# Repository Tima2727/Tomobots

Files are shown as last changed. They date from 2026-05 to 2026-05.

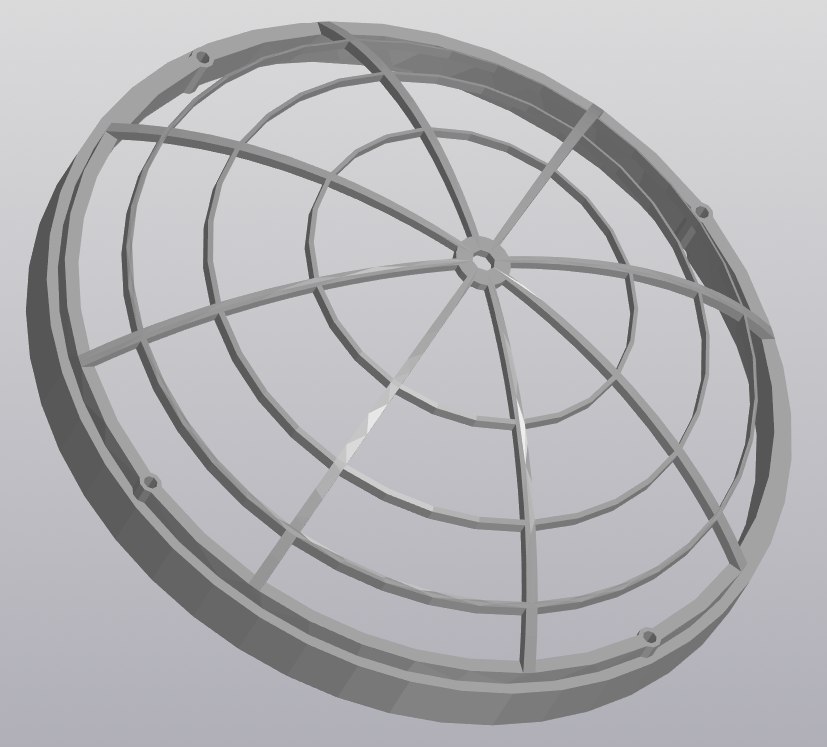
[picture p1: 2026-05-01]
Case/Photos/Lower_part.jpg

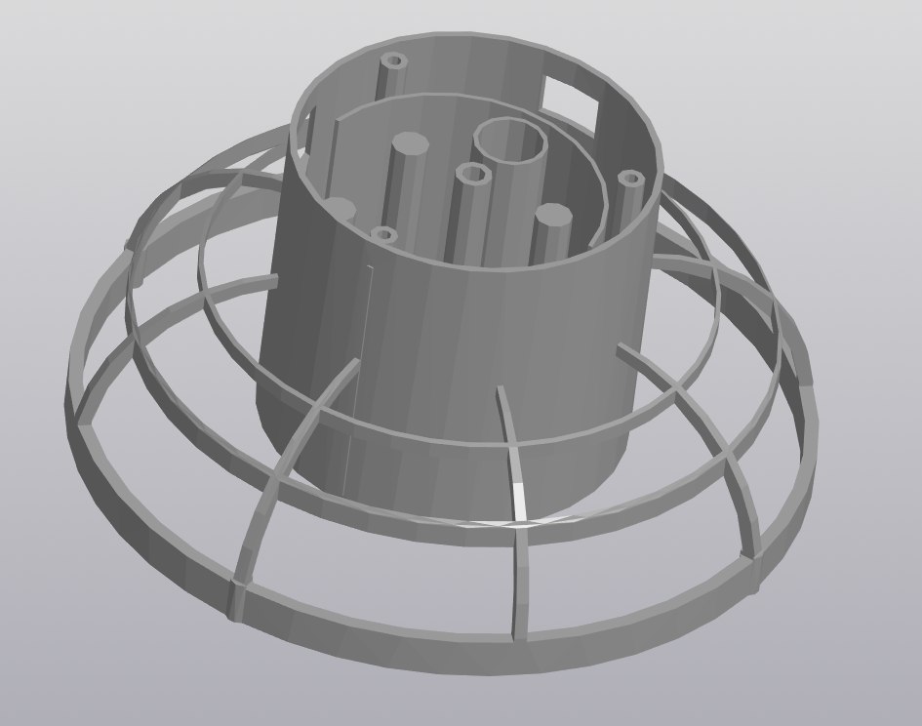
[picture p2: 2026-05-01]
Case/Photos/Upper_part.jpg

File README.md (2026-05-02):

# Tomobots: Роевая система роботов для поиска людей в завалах

**Tomobots** — это инженерный проект по разработке роя компактных и дешевых автономных роботов, предназначенных для первичной разведки в зонах обрушений зданий и землетрясений. Система призвана заменить дорогостоящие и крупногабаритные платформы, обеспечивая быструю локализацию пострадавших даже в труднодоступных «карманах» и щелях.

## Основные особенности

* **Роевая архитектура**: Массовое развертывание сотен простых устройств делает систему устойчивой к потере отдельных единиц.
* **Уникальная проходимость**: Роботы имеют тарелкообразную форму (диаметр 8-10 см) и симметричную конструкцию, позволяющую продолжать движение даже после переворачивания.
* **Низкая себестоимость**: Ориентировочная стоимость в сотни раз меньше аналогов.
* **Ретрансляционная сеть**: При обнаружении человека роботы формируют цепочку передачи радиосигнала до поверхности без необходимости в сложной навигации.

## Технические характеристики прототипа

| Параметр | Значение |
| :--- | :--- |
| **Габаритный диаметр** | 10 см |
| **Масса** | 32 г |
| **Вычислительный модуль** | ESP-12 (ESP8266) |
| **Время работы** | ≈ 25 мин |
| **Материал корпуса** | PLA |

## Алгоритм работы

1.  **Развертывание**: В зону завала запускается партия из ~100 роботов.
2.  **Зондирование**: Роботы выполняют циклы коротких взлетов и хаотичных перемещений.
3.  **Активация**: Пострадавший нажимает высококонтрастную кнопку на роботе.
4.  **Режим маяка**: Активированный робот включает яркую RGB-подсветку и начинает передачу сигнала.
5.  **Локализация**: Ближайшие роботы ретранслируют сигнал на поверхность, где система антенн определяет примерное местоположение цели.

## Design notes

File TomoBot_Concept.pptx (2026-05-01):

## TomoBot

Маленькие роботы для больших вызовов

Университет ИТМО
Санкт-Петербург
01 сентября 2025

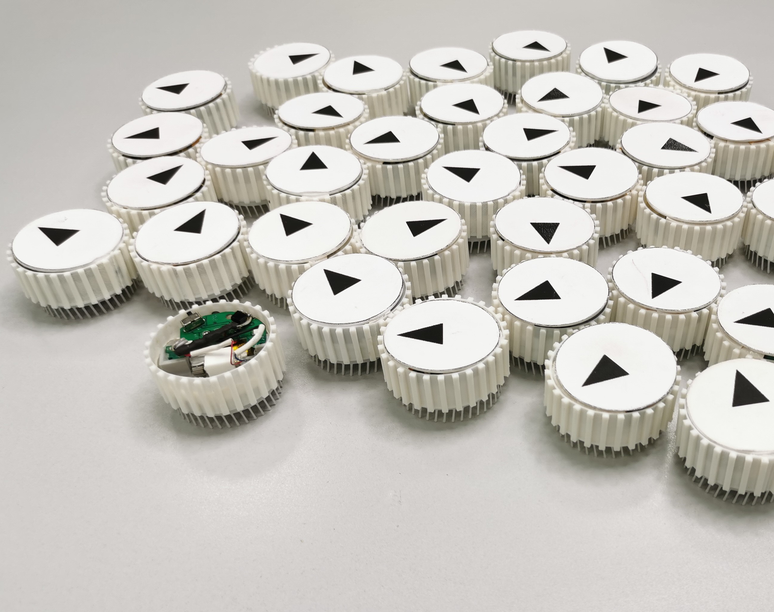
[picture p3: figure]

## Исследование завалов и опасных сред

Большой рой роботов по 800р вместо одного дорогого робота или эндоскопа

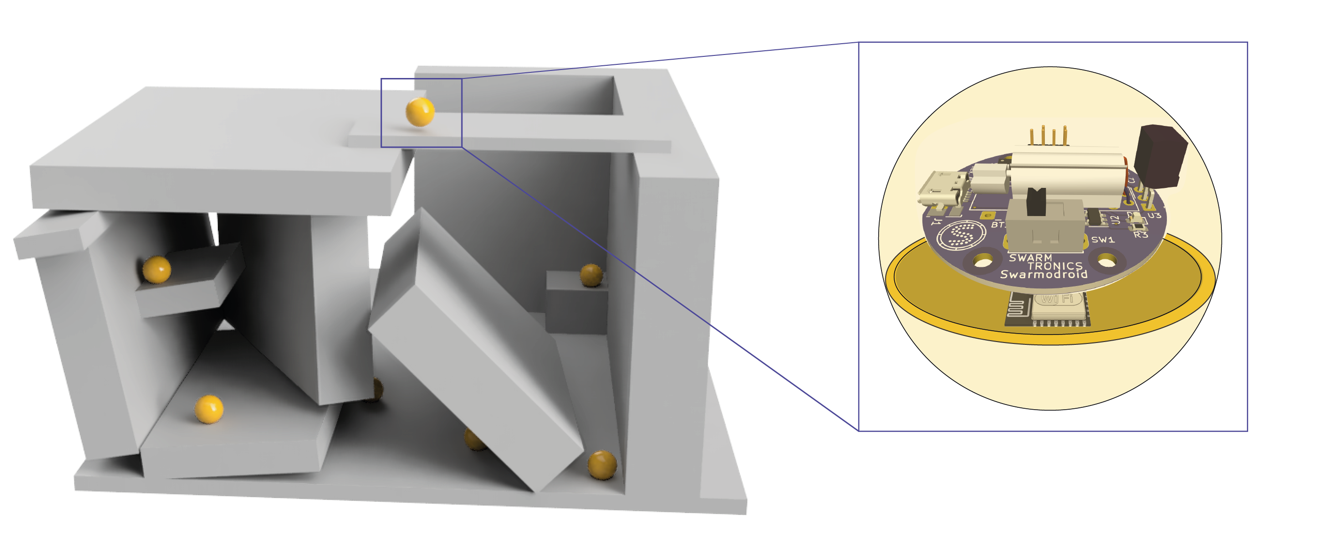
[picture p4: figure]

Цель: определять геометрию завала и число людей в сознании за несколько минут

- Радиомаяк
- LED
- Кнопка для сигнала бедствия

TRL 1

## Исследование завалов и опасных сред

Идея:

Wicked Ball

ESP8266

Wi-Fi tomography

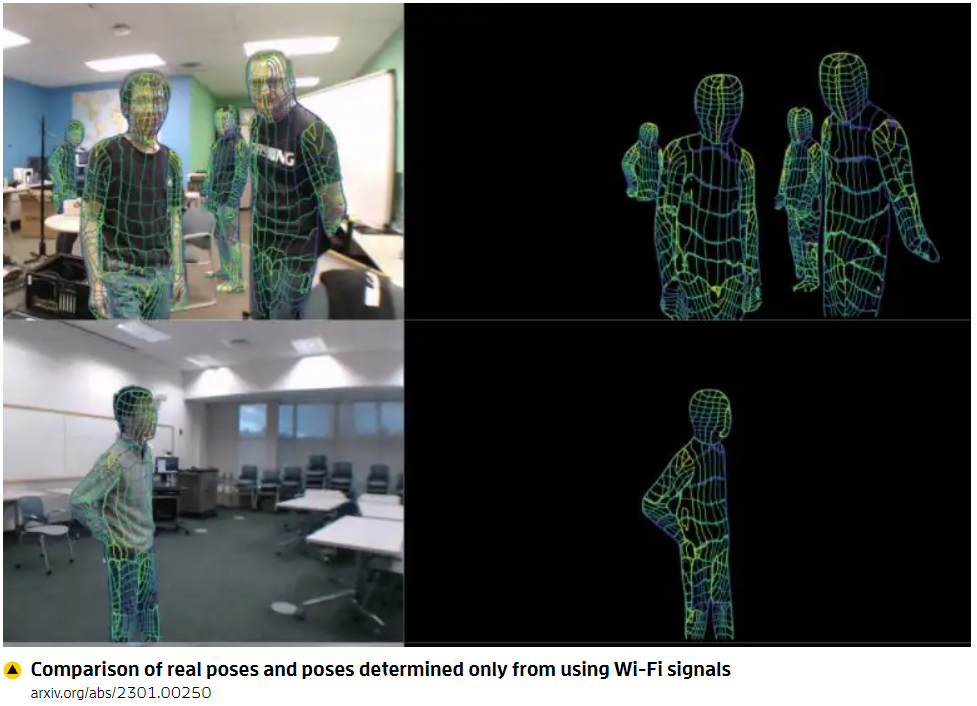
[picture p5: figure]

J. Geng, et al., DensePose From WiFi (2023)
https://arxiv.org/abs/2301.00250

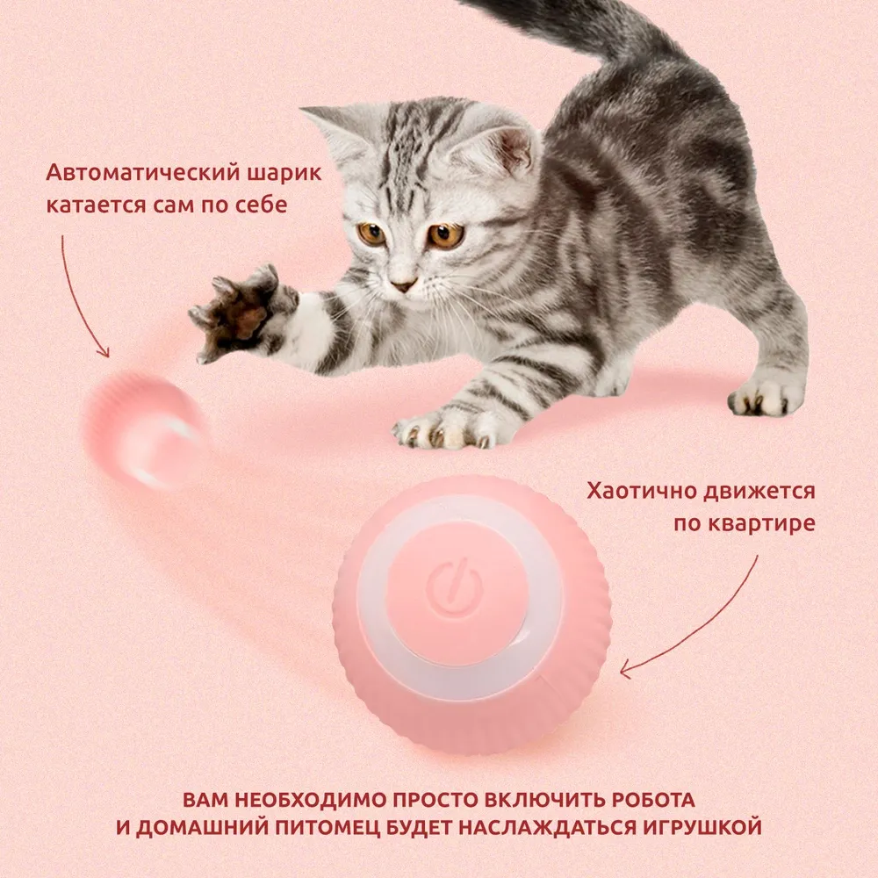
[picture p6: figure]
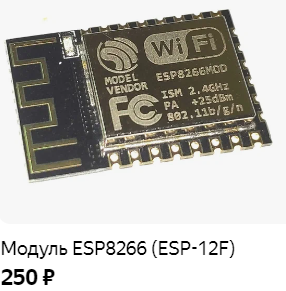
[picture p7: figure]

+

+

## Контакты

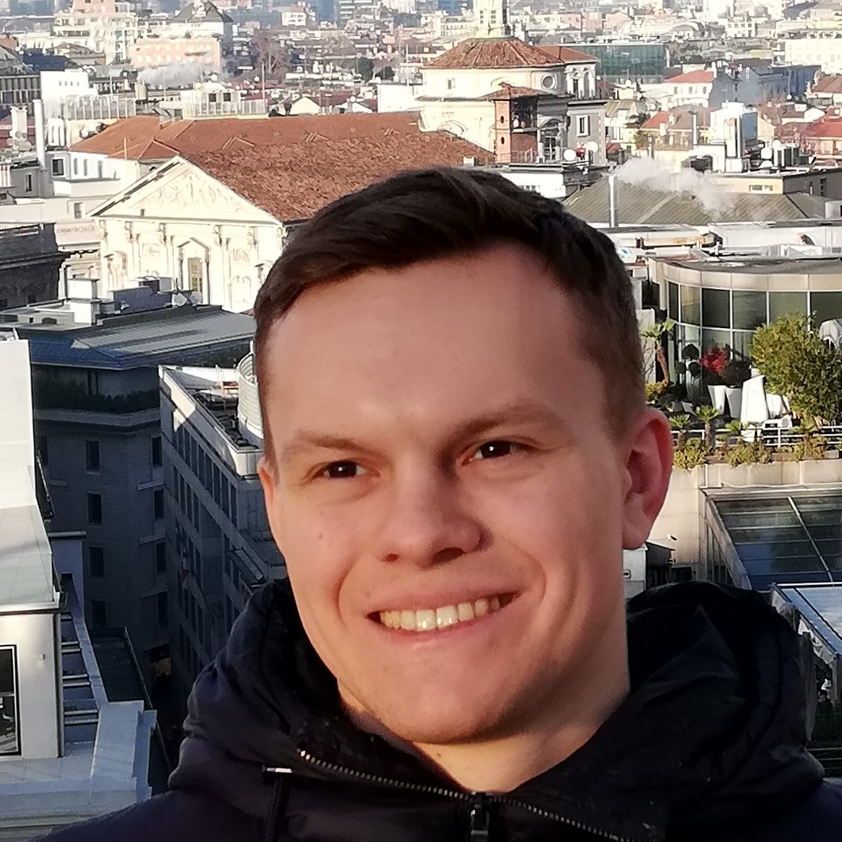
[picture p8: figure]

Никита Олехно
nikita.olekhno@metalab.ifmo.ru

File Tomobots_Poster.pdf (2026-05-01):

СОЗДАНИЕ НОВОГО КОРПУСА И НОВОЙ ПЕЧАТНОЙ ПЛАТЫ, ИХ ИСПЫТАНИЕ.
РАЗРАБОТКА ПРОТОКОЛА СВЯЗИ МЕЖДУ РОБОТАМИ И СИСТЕМОЙ АНТЕНН НА ПОВЕРХНОСТИ.
РАЗРАБОТКА | КОНФИГ УРАЦИИ | ПРИЕМНЫХ | АНТЕНН | И
ПРОГРАММНОГО ОБЕСПЕЧЕНИЯ ДЛЯ ОБРАБОТКИ ПОСТ УПАЮЩИХ ИЗ ЗАВАЛА СИГНАЛОВ.
ПОЛЕВЫЕ | ИСПЫТАНИЯ | РОЯ | РОБОТОВ | В | УСЛОВИЯХ.
ИМИТИРУЮШИХ ЗАВАЛ.

ДОПОЛНЕНИЕ РОБОТА ИК-ДАТЧИКОМ ДЛЯ ОБНАРУЖЕНИЯ ТЕПЛОВОГО ИЗЛУЧЕНИЯ ЧЕЛОВЕКА. РЕАЛИЗАЦИЯ ПОИСКА МОБИЛЬНЫХ ТЕЛЕФОНОВ С ПОМОЩЬЮ WI-FI-МОДУЛЯ.
ДОБАВЛЕНИЕ ДАТЧИКА ДАВЛЕНИЯ ДЛЯ ОЦЕНКИ ГЛУБИНЫ И БОЛЕЕ ИНФОРМАТИВНОГО ОБСЛЕДОВАНИЯ ПОЛОСТЕЙ. ИСПОЛЬЗОВАНИЕ ЛЕТАЮЩИХ РОБОТОВ КАК ПОДВИЖНЫХ УЗЛОВ ДЛЯ ПОСТРОЕНИЯ КАРТЫ ЗАВАЛА (ФУНКЦИЯ ТОМОГРАФИИ).

ПРОБЛЕМА РАЗВЕДКИ В ЗАВАЛАХ: УЗКИЕ ЩЕЛИ (<30 СМ), НЕСТАБИЛЬНОСТЬ ПОСТРОЕК, ПЫЛЬ.
СУЩЕСТВУЮЩИЕ РОБОТЫ ЧАСТО БОЛЬШИЕ, ДОРОГИЕ И ПЛОХО АДАПТИРУЮТСЯ К ИЗМЕНЯЮЩИМСЯ УСЛОВИЯМ.

НАШЕ РЕШЕНИЕ: МАССОВЫЙ ЗАПУСК РОЯ МАЛЕНЬКИХ ДЕШЁВЫХ, ЛЕТАЮЩИХ РОБОТОВ, ПОТЕРЯ ЧАСТИ КОТОРЫХ НЕ НЕСЁТ УЩЕРБА ВСЕЙ СИСТЕМЕ.

# АЛГОРИТМ РАБОТЫ

### 1. РАЗВЁРТЫВАНИЕ

С | ПОВЕРХНОСТИ | ЗАВАЛА | В | НЕСКОЛЬКИХ | ТОЧКАХ
ВЫПУСКАЕТСЯ ПОРЯДКА СОТНИ РОБОТОВ.

### 2. ЗОНДИРОВАНИЕ

КАЖДЫЙ РОБОТ ОСУЩЕСТВЛЯЕТ ХАОТИЧНОЕ ДВИЖЕНИЕ С ПАУЗАМИ — ЭТО ПРЕДОСТАВЛЯЕТ РОЮ ВОЗМОЖНОСТЬ ОБСЛЕДОВАТЬ РАЗЛИЧНЫЕ УРОВНИ И ПОЛОСТИ.

3.ОБНАРУЖЕНИЕ
РОБОТ | ОСНАЩЁН | КРУПНОЙ | КНОПКОЙ | С | ЯРКОЙ
ПОДСВЕТКОЙ. ПОСТРАДАВШИЙ, ЗАМЕТИВ ЕГО, АК ТИВИРУЕТ КНОПКУ. РОБОТ НЕМЕДЛЕННО ФИКСИРУЕТ КОНТАК Т И ПЕРЕКЛЮЧАЕТСЯ В РЕЖИМ МАЯКА.

4.ОРГАНИЗАЦИЯ СЕТИ
В | РЕЖИМЕ | МАЯКА | РОБОТ | НАЧИНАЕТ | ПОСТОЯННО
ПЕРЕДАВАТЬ СИГНАЛ О НАЙДЕННОМ ЧЕЛОВЕКЕ И СВОЙ ИДЕНТИФИКАЦИОННЫЙ НОМЕР. БЛИЖАЙШИЕ К НЕМУ РОБОТЫ, ПОЛУЧИВ СИГНАЛ, РЕТРАНСЛИРУЮТ ЕГО ДАЛЬШЕ ПО ЦЕПИ, ПОКА ОН НЕ ДОСТИГНЕТ ПОВЕРХНОСТИ.

### 5. ЛОКАЛИЗАЦИЯ

УСТАНОВЛЕННАЯ НА ПОВЕРХНОСТИ УСИСТЕМА ИЗ АНТЕНН ЛОКАЛИЗУЕТ ПРИШЕДШИЙ СИГНАЛ И ПО КОЛИЧЕСТВУ ПОЛУЧЕННЫХ СИГНАЛОВ ИЗ ОПРЕДЕЛЁННОЙ ОБЛАСТИ ПОЗВОЛЯЕТ ОЦЕНИТЬ МЕСТОПОЛОЖЕНИЕ ПОСТРАДАВШИХ.

РОЙ АВТОНОМНЫХ ЛЕТАЮЩИХ МИКРОРОБОТОВ Д Л Я ПОИСК А ЛЮД

# TOMOBOTS

ЕЙ В ЗАВА Л А Х

КОМАНД А: Т. ВЕЧК АНОВ, В. ТИМОФЕЕВ, В. ЛЕЗАРЕВ РУКОВОДИТЕЛИ: Н.А. ОЛЕХНО, А.А. ДМИТРИЕВ

# ПРОТОТИП

1) КРЫШКИ НА КОНЦАХ ВАЛА
2) МОДУЛЬ ESP-12
3) БЕСКОЛЛЕКТОРНЫЙ МОТОР
4) АККУМУЛЯТОР
5) ЛОПАСТИ
6) СЕТЧАТЫЙ КОРПУС
7) ОСЕВОЙ ВАЛ

СТРУКТУРА ПРОТОТИПА

ПРИНЦИПИАЛЬНАЯ СХЕМА ПРОТОТИПА

ПРОТОТИП | ПРЕДСТАВЛЯЕТ | СОБОЙ | ПОДВИЖНУЮ
ПЛАТФОРМУ | ЭЛЛИПСОИДАЛЬНОЙ | ФОРМЫ,
ПОВТОРЯЮЩУЮ ГЕОМЕТРИЮ БУДУЩЕГО ЛЕТАЮЩЕГО РОБОТА. В НЁМ ИНТЕГРИРОВАНЫ ВСЕ ОСНОВНЫЕ КОМПОНЕНТЫ ФИНАЛЬНОЙ КОНСТРУКЦИИ.

ОСНОВНЫЕ КОМПОНЕНТЫ СХЕМЫ

### 1. МОДУЛЬ ESP-12 (U1) 2. БЕСКОЛЛЕК ТОРНЫЙ МОТОР QX-6A-N (M1) 3. АККУМУЛЯТОР LP601120 3.7В (BT1) 4. СВЕТОДИОД TO-2013BC-MRE (D1) 5. РАЗЪЁМ MICRO-USB KLS1-233-0-0-1-T (J1) 6. КОНТРОЛЛЕР ЗАРЯДА STC4054 (U3)

# АКТУАЛЬНОСТЬ

# ПЛАНЫ РАЗВИТИЯ

СЛЕДУЮЩИЙ СЕМЕСТР

ПЕРСПЕКТИВА

РАСПОЛОЖЕНИЕ ЭЛЕМЕНТОВ

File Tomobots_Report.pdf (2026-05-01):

Университет ИТМО

Физический факультет

Отчет по семестровому инженерному

проекту

## Tomobots

Исполнители: Тимофеев Вячеслав Вечканов Тимофей Лезарев Всеволод

Руководители: Никита Олехно
| Алексей Дмитриев

Санкт-Петербург
2026

## Содержание

1 Актуальность | 2
2 Схема решения | 3
3 Экономико-техническое обоснование | 5
4 Прототип | 6
5 Инструкция для пользователя | 11
6 Команда проекта | 12
7 План дальнейшего развития | 13
Список источников | 16

## 1 Актуальность

### 1.1 Общие сведения о завалах

В случаях, когда происходят обрушения зданий и землетрясения, первичная разведка значительно осложняется множеством физических ограничений, таких как: узкие проёмы, неустойчивые опорные плоскости, запылённость и фактическая нулевая видимость. Типовые схемы обрушений формируют «карманы» и щели, недоступные для человека и габаритной техники. Критическим фактором становится время: чем быстрее удаётся обнаружить и локализовать пострадавших, тем выше шанс успешной эвакуации.

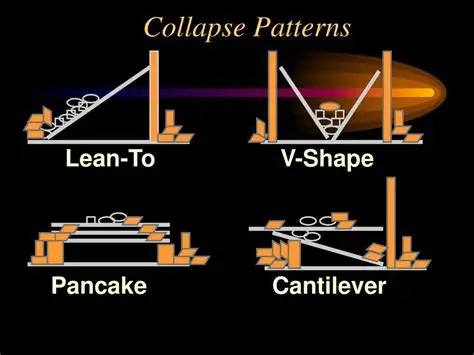
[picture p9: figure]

Рис. 1: Схематично: типовые схемы обрушения (из [4]).

Практика стандартизированных испытаний и инженерные источники указывают на характерные «узкие места» порядка 20–30 см и наклонные осыпи с углами около 30◦ −45◦
(по данным из [1, 3]), что требует компактных и устойчивых к опрокидыванию систем. На этом фоне востребованы решения, которые можно массово развернуть за минуты, которые безопасны при контакте с завалом, допускают потерю отдельных единиц без провала миссии и предоставляют спасателям однозначную «наводку» на человека.

### 1.2 Обзор существующих решений

Наземные платформы (гусеничные/колёсные):
В реальных завалах существующие системы часто физически не проходят в локальные пустоты; к тому же масса и стоимость остаются высокими, а риск заклинивания велик ([1]). Сильные стороны — высокая грузоподъёмность, манипуляторы, длительная работа; слабые — ограниченная проходимость, необходимость подготовленных маршрутов и стоимость.

Воздушные решения (квадрокоптеры, БПЛА):
Складывающиеся и трансформируемые конструкции демонстрируют проникновение в стеснённые пространства и пролёты через узкие проёмы ([11, 10]). Однако в завалах им мешают пыль, ограниченная энергоёмкость, отсутствие стабильной навигации и связи, а удар по лопастям ведёт к отказу. Управление в тесных каналах требует высокой квалификации пилота или сложной автономии.

Роевые и недорогие платформы:
Опыт работы платформ вроде [9, 8] показывает, что сотни простых роботов могут работать вместе и не «ломаются» как система, даже если часть из них выходит из строя. Но есть важные ограничения: данные эксперименты проводятся на ровных лабораторных площадках, что оставляет октрытым вопрос о надёжности связи и ориентирования в условиях завалов. Кроме того, роботы должны пролезать через узкие места, экономно расходовать энергию и пробивать радиосигналом путь к поверхности.

Вывод

Текущие решения покрывают отдельные сценарии, однако на сегодняшний день существует необходимость их объединения и создания вариантов, которые одновременно: компактны и безопасны при контакте с обломками, дёшевы в масштабировании до сотен экземпляров и сохраняют функциональность при перевороте/ударе.

Предлагаемый подход:
Мы закрываем этот пробел роевой системой компактных роботов-маяков: они хаотично обследуют завал, а при активации пострадавшим формируют ретрансляционную цепочку до поверхности, обеспечивая быструю локализацию без сложной картографии и дорогостоящих сенсоров. Это сочетает массовое развёртывание, отказоустойчивость роя и триггерную детекцию человеком.

## 2 Схема решения

### 2.1 Алгоритм работы роя роботов

Проектом разрабатывается система на базе роя автономных летающих роботов тарелкообразной формы (диаметр 8-10 см). Система функционирует по следующему алгоритму:

1. Массовое развертывание. С поверхности завала в нескольких точках выпускается порядка сотни роботов.

2. Пассивно-активное зондирование. Каждый робот осуществляет хаотичное движение в объёме завала. Алгоритм полёта предполагает циклическое выполнение коротких взлётов, горизонтальных перемещений в случайном направлении и пауз, при которых робот не двигается. Взлёты осуществляются поочерёдно в обоих направлениях за счёт симметричных лопастей и смены полярностей на моторе, благодаря чему робот продолжает функционировать при переворачивании. Это позволяет роботу обследовать различные уровни и полости, а также предоставляет временное окно для взаимодействия с пострадавшим.
3. Обнаружение и активация. Робот оснащён высококонтрастной кнопкой с подсветкой. Пострадавший, обнаружив рядом робота, нажимает кнопку, после чего робот начинает передавать сигнал о найденном человеке.
4. Организация ретрансляционной сети. Активированный робот переходит в режим маяка. Он начинает постоянно светиться и передавать сигнал о найденном человеке и свой идентификационный номером. Близжайщие из роя роботы, получив сигнал, ретранслируют его дальше по цепи, пока он не выберется на поверхность.
5. Локализация пострадавших. На поверхности устанавливается система из антенн, которая локализует пришедший сигнал и по количеству полученных сигналов из определённой области позволяет приблизительно оценить местоположение пострадавших.

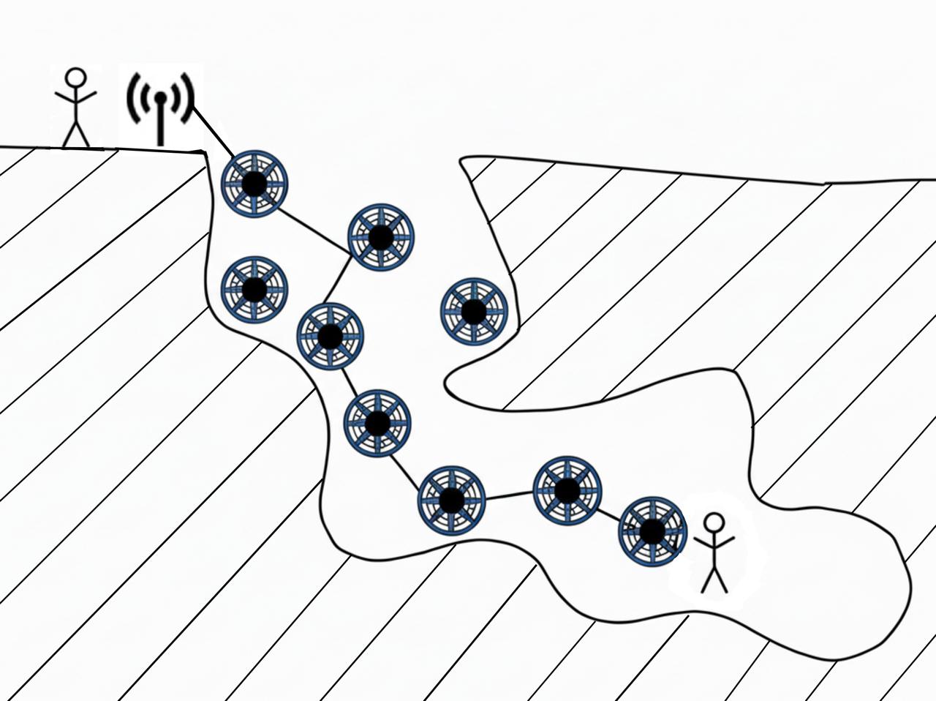
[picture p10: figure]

Рис. 2: Схема работы роботов

### 2.2 Физико-технические основы

Динамика:
Сетчатый корпус минимизирует массу и обеспечивает проход воздуха от расположенного внутри пропеллера. Также ось вращения пропеллера выходит из корпуса и на ее концах оснащена специальными крышками, так что при работе пропеллера на малых оборотах крышки также вращаются и цепляются за землю, за счёт чего обеспечивается хаотичное передвижение в горизонтальном направлении.

Управление:
Полетная логика (взлёт/падение, случайные смещения) реализована на программируемом модуле ESP-12, который управляет мотором, обеспечивающим вращение лопастей.

Связь:
Для организации надёжной многоузловой сети разрабатывается специальный протокол связи в нелицензируемом ISM-диапазоне, оптимизированный для низкой скорости передачи данных, но высокой помехоустойчивости.

## 3 Экономико-техническое обоснование

Вычислительная платформа:
Программируемый Wi-fi модуль (на базе ESP8266).
Обоснование: наличие встроенного Wi-Fi/радиомодуля, достаточная для базовой логики производительность, низкая стоимость, возможность программирования в Arduino IDE.

Корпус:
3D-печать методом FDM из лёгкого PLA или PETG с решётчатой структурой. Обоснование: высокие скорость прототипирования и потенциал масштабирования, формирование сложных аэродинамических форм при минимальной массе.

Энергосистема:
Литий-полимерный аккумулятор (Li-Po) малой ёмкости (110 мА·ч). Обоснование: достаточная ёмкость и малые габариты.

Cистема реагирования:
Кнопка с защитой от ложных срабатываний, RGB-светодиод высокой яркости. Обоснование: стабильное срабатывание кнопки только от нажатий человека, легкость в её обнаружении.

В смете (Таблица 1) указаны компоненты, которые будут использоваться в финальной версии роботов.

Таблица 1: Смета на одного Tomobot’а
Наименование | Ед. изм. | Стоимость, руб | Кол-во | Сумма, руб
Модуль ESP-12 (ESP8266) Бесколлекторный мотор Аккумулятор Светодиод TO-2013BC-MRE Драйвер мотора L9110S Переключатель Ось привода (вал) Разъём micro-USB KLS1-233-0-0-1-T Контроллер заряда STC4054 Стабилизатор питания AMS1117-3.3V Транзистор AO3400 Резистор 10k Резистор 680 Резистор 5k1 Конденсатор 100нФ | шт. шт. шт. шт. шт. шт. шт. шт. шт. шт. шт. шт. шт. шт. шт. | 190 600 500 8 20 11 8 11 130 6 4 0.7 0.7 0.7 2 | 1 1 1 1 1 1 1 1 1 1 1 2 1 1 1 | 190 600 500 8 20 11 8 11 130 6 4 1.4 0.7 0.7 2
Итого | | | | 1493.8

В отличие от аналогов, наша система имеет ориентировочную себестоимость одного робота около 1500 рублей.

Это обеспечивает беспрецедентное ценовое преимущество. Например, для обследования типового завала площадью 100 м² потребуется около 200 роботов. Стоимость такой партии составит около 300 000 рублей. Для сравнения, один гусеничный робот сопоставимой функциональности стоит от 500 000 рублей, при этом он не способен одновременно охватывать множество полостей и не обладает отказоустойчивостью роя.

## 4 Прототип

На текущем этапе разработан и собран функциональный прототип робота, предназначенный для экспериментальной отработки ключевых принципов работы системы: механизма перемещения, базовой логики поведения и интеграции электронных компонентов.

### 4.1 Конструкция и состав

Прототип представляет собой наземную подвижную платформу тарелкообразной формы, повторяющую целевую геометрию будущего летающего робота (Рис. 3). В нём интегрированы все основные компоненты финальной конструкции, за исключением драйвера силового мотора, что позволило сосредоточиться на изучении динамики и управлении:

1. Программируемый Wi-fi модуль ESP12 (ESP8266) в качестве вычислительного ядра.
2. Бесколлекторный мотор, вращающий лопасти на оси.
3. Система питания на базе Li-Po аккумулятора ёмкостью 110 мА·ч с контроллером заряда TC4054 и стабилизатором напряжения AMS1117.

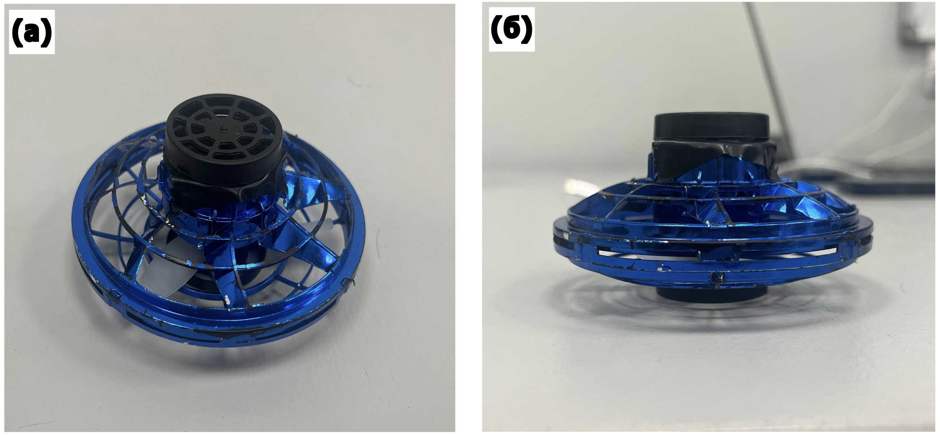
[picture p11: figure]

Рис. 3: Фотография собранного прототипа.

### 4.2 Принцип работы прототипа

Прототип реализует механизм хаотичного наземного перемещения. При вращении мотора лопасти, закреплённые на выступающей оси, взаимодействуют с опорной поверхностью. На малых оборотах специальные крышки на концах оси цепляются за грунт, обеспечивая случайные поступательные смещения и вращение корпуса. Данный режим является упрощённым аналогом фазы «паузы и смещения» в целевом алгоритме полёта и служит для изучения поведения робота в контакте с неструктурированной поверхностью, имитирующей завал.

### 4.3 Электрическая схема и модель корпуса

Для обеспечения повторяемости и дальнейшей разработки подготовлена полная документация прототипа. Также в смете (Таблица 2) указаны компоненты, используемые в прототипе.

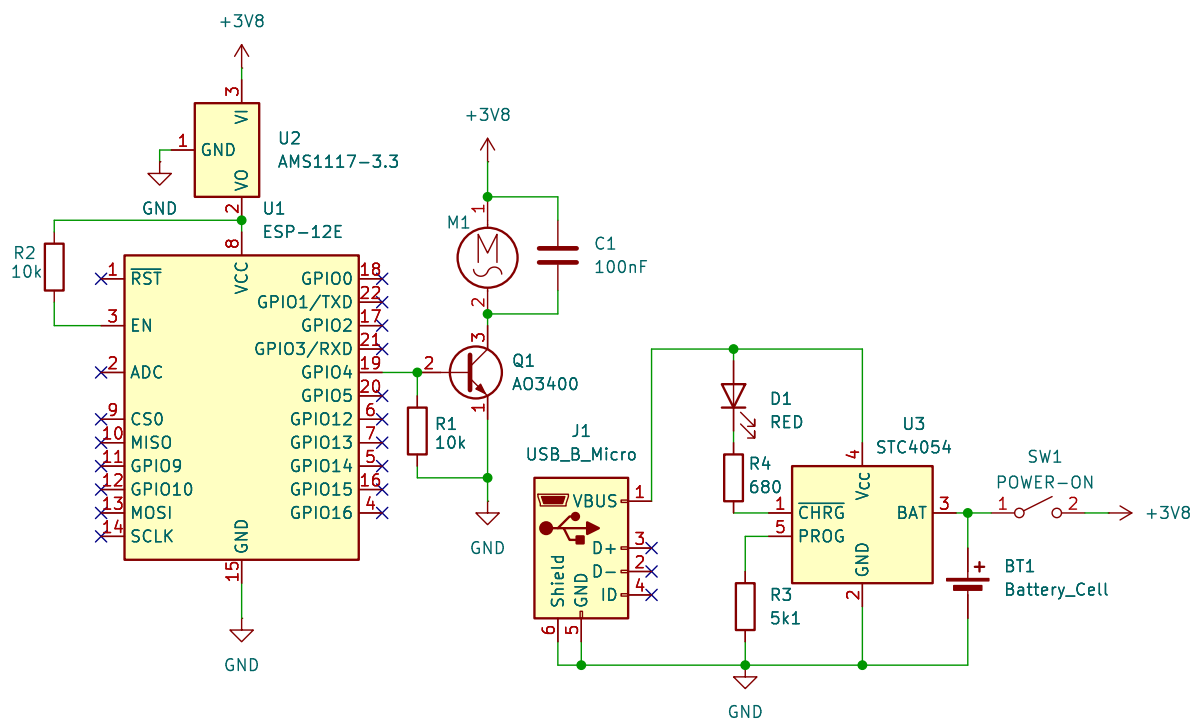
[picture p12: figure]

Рис. 4: Электрическая принципиальная схема прототипа.

На рисунке 4 изображена схема электрическая принципиальная прототипа. Для управления мотором M1, QX-6A-N и для приёма-отправки сигналов используется модуль ESP-12E, питание 3.3В к нему поступает через стабилизатор напряжения U2, который понижает исходное нпряжение питания от батарейки BT1 3.8В до напряжения соответственно необходимого для работы модуля ESP-12E. Для включения модуля также необходимо напряжение на пине EN, который соответственно через токоограничительный резистор R2 соединен с питанием модуля. На выход GPIO4 согласно прошивке модуля циклически подаётся различный широтно-импульсно модулированный сигнал с высоким логическим уровнем 3.3В. При высоком логическом уровне полевой транзистор Q1 открыт и соответствующий полюс мотора соединен с общим проводом. Параллельно мотору установлен конденсатор C1, сглаживающий ШИМ при низких частотах. Также к GPIO4 подсоединен подтягивающий резистор R1 к общему проводу, необходимый для фиксирования низкого логического уровня и предотвращения ложных срабатываний. Для зарядки используется порт Micro-USB, который соединён с контроллером зарядки STC4054. К пину CHRG через токоограничительный резистор R4 подключен диод D1, который является индикатором зарядки. Пин PROG соединен с общим проводом через резистор R3, что устанавливает ограничение тока зарядки батареи. Положительный контакт батареи соединён с пином BAT, отрицательный с общим проводом. На выходе питания установлен переключатель SW1, который отвечает за перевод робота во включенное состояние и наоборот.

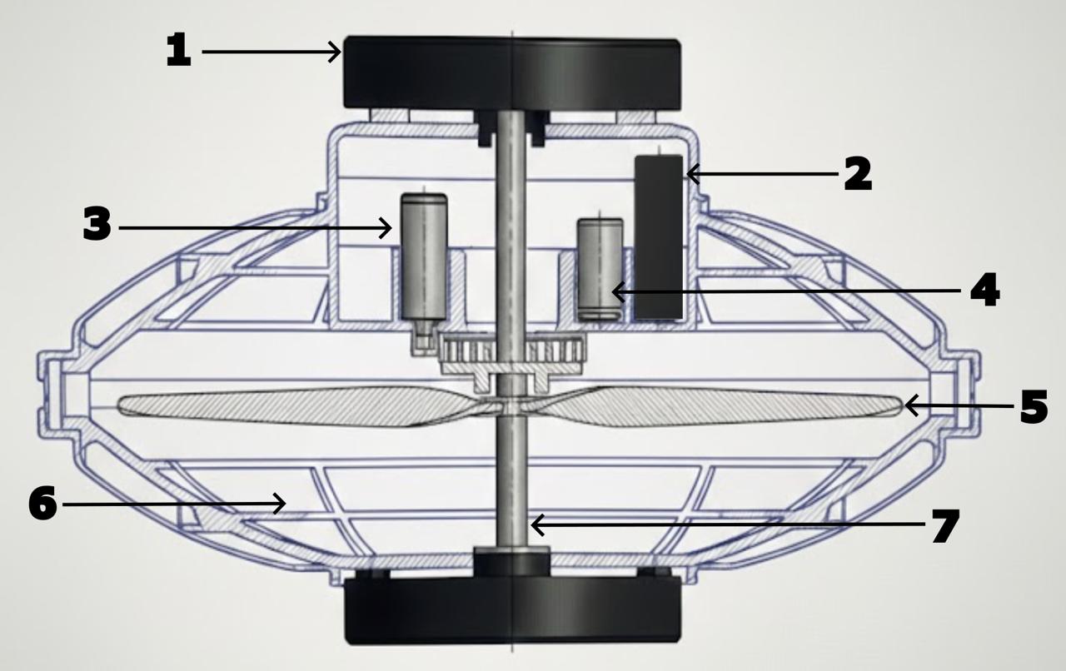
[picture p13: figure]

Рис. 5: Схематичный рисунок робота в разрезе: 1) Крышки на концах вала
2) Додуль ESP-12 3) Бесколлекторный мотор 4) Аккумулятор 5) Лопасти 6) Сетчатый корпус 7) Осевой вал

Таблица 2: Смета прототипа
Наименование | Ед. изм. | Стоимость, руб | Кол-во | Сумма, руб
Модуль ESP-12 (ESP8266) Бесколлекторный мотор QX-6A-N Аккумулятор LP601120 3.7 В Светодиод TO-2013BC-MRE Переключатель Ось привода (вал) Разъём micro-USB KLS1-233-0-0-1-T Контроллер заряда STC4054 Стабилизатор питания AMS1117-3.3V Транзистор AO3400 Резистор 10k Резистор 680 Резистор 5k1 Конденсатор 100нФ | шт. шт. шт. шт. шт. шт. шт. шт. шт. шт. шт. шт. шт. шт. | 190 175 130 8 11 8 11 130 6 4 0.7 0.7 0.7 2 | 1 1 1 1 1 1 1 1 1 1 2 1 1 1 | 190 175 130 8 11 8 11 130 6 4 1.4 0.7 0.7 2
Итого | | | | 677,8

### 4.4 Измеренные характеристики и выявленные пробле-

мы

В процессе испытаний прототипа были получены следующие ключевые характеристики и определены направления для доработки:

Таблица 3: Основные параметры и результаты испытаний прототипа
Параметр | Результат / Значение
Габаритный диаметр | 10 см
Масса (с аккумулятором) | 32 г
Время непрерывной работы | ≈ 25 мин
Тип перемещения | Случайные вращения и посту-пательные смещения по по-верхности

Выявленная ключевая проблема: Установленный в прототипе мотор не обладает достаточной мощностью для реализации запланированного цикла кратковременных взлётов. Это подтверждает необходимость перехода к более мощному мотору в следующей итерации разработки.

### 4.5 Роль прототипа в проекте

Несмотря на ограничения, текущий прототип успешно выполняет свои задачи:

1. Проверка функциональности: Подтверждена работоспособность и совместимость выбранных компонентов (ESP-12, система питания).
2. Исследование динамики: Изучено поведение корпуса заданной формы при контакте с поверхностью, что критически важно для фазы паузы.
3. Платформа для отладки ПО: Обеспечена возможность тестирования базового кода управления.

Таким образом, данный прототип служит фундаментальным подтверждением возможности создания продукта. На его основе в следующем семестре будет создан полнофункциональный летающий образец с более мощным мотором и доработанным алгоритмом.

## 5 Инструкция для пользователя

### 5.1 Подготовка к работе

Установите по углам исследуемой области приёмные антенны и проверьте их работоспособность в тестовом режиме.

Убедитесь, что все роботы в пусковой партии заряжены (индикатор на устройстве горит зелёным).

Визуально оцените зону завала и выберите 3-5 точек для запуска в предполагаемой зоне поиска.

### 5.2 Запуск

В каждой выбранной точке последовательно выпустите роботов: извлеките из транспортного контейнера и включите питание.

После запуска роботы начнут хаотичное движение внутри завала (короткие взлёты и перемещения с паузами).

### 5.3 Мониторинг

Следите за показаниями в заранее установленном ПО на компьютере/планшете.

Отсутствие сигнала означает, что триггерное событие (обнаружение пострадавшего и нажатие кнопки) ещё не произошло.

### 5.4 Действия при обнаружении

При нажатии пострадавшим кнопки на роботе формируется «цепочка» — маяки фиксируются и светятся; сигнал ретранслируется к поверхности.

Цепочка светящихся роботов указывает направление и примерный путь к пострадавшему.

Начните точечную разборку завала, двигаясь от крайнего (видимого на поверхности) робота вдоль линии зафиксированных маяков.

### 5.5 Возможные проблемы

Приёмник регистрирует слабый или прерывистый сигнал:

Переместитесь по периметру зоны, чтобы найти позицию с лучшим приёмом; цепочка могла сформироваться в глубине, и сигнал пробивается только в отдельных точках.

Робот не взлетает / не реагирует:

Считайте устройство неисправным, аккуратно извлеките его из зоны поиска и замените другим. Система роя рассчитана на отказ отдельных единиц без потери общей функциональности.

## 6 Команда проекта

Название будущего стартапа: Tomobots.

### 6.1 Команда и зоны ответственности

Вечканов Тимофей — инженер (электронная часть). Схемотехника и PCB (ESP-12/ESP8266; драйверы, зарядка и стабилизация питания), прошивка на C/Arduino IDE, проектирование радиопротокола в ISM-диапазоне, стендовые испытания электроники.
Вклад в отчёт: «Схема решения», «Выбор компонентов и технологий», «Связь», «Смета прототипа».

Тимофеев Вячеслав — инженер (механическая часть). CAD-моделирование, 3D-печать (FDM PLA/PETG), конструкция решётчатого корпуса, узел вала
и лопастей, сборка и прочностные/ударные испытания.
Вклад в отчёт: «Прототип», иллюстрации и фото.

Лезарев Всеволод — инженер (интеграция и компановка отчётов). Полевые тесты, ведение репозитория и сборки материалов (презентация/постер). Вклад в отчёт: «Инструкция для пользователя», «План дальнейшего развития», компоновка и форматирование.

### 6.2 Научные руководители

Алексей Дмитриев — научный руководитель. Н.с. Физико-технического факультета, к.ф.-м.н.
Роль в проекте: научная экспертиза, корректность формулировок, финальная проверка текстов.

Никита Олехно — научный руководитель. Доцент Физико-технического факультета, к.ф.-м.н.
Роль в проекте: постановка исследовательских задач, контроль методологии и научной новизны.

### 6.3 Контакты

ФИО | Роль | E-mail
Вечканов Т. Тимофеев В. Лезарев В. Дмитриев А. Олехно Н. | электроника механика интеграция/ПО науч. рук. науч. рук. | timofei.vechkanov@metalab.ifmo.ru v.timofeev@metalab.ifmo.ru vsevolod.lezarev@metalab.ifmo.ru alexey.dmitriev@metalab.ifmo.ru nikita.olekhno@metalab.ifmo.ru

## 7 План дальнейшего развития

### 7.1 Следующий семестр

Создание и апробация изделия:
Новый корпус и новая печатная плата; сборка и функциональные испытания экспериментального образца.

Разработка протокола связи:
Создание и испытание прототипа с базовой логикой полёта (взлёт/посадка/случайное смещение).

Система приёма сигнала и локализации:
Разработка конфигурации приёмных антенн и специализированного ПО для обработки поступающих сигналов.

Интеграция и полевые испытания:
Комплексные испытания роя из 5-10 роботов в условиях, имитирующих завал (лабиринт из труб и картона).

### 7.2 Перспектива

Автономное обнаружение:
Замена/дополнение тактильной кнопки пассивным ИК-датчиком (PIR) для детекции теплового излучения человека; обнаружение близлежащих телефонов с использованием Wi-Fi-модуля.

Улучшение навигации:
Добавление датчика давления для оценки глубины и более интеллектуально-

го обследования полостей.

Гибридная томография:
Использование летающих роботов как подвижных узлов для предварительного построения карты завала на основе анализа уровней принимаемого сигнала между ними и базовыми станциями.

Создание нового корпуса робота: Планируется заменить текущий корпус на новый для упрощения масштабирования производства (Рис. 6, 7).


Рис. 6: Новый корпус: верхняя часть


Рис. 7: Новый корпус: нижняя часть

## Список источников

[1] NIST, ASTM. Standard Test Methods for Response Robots. U.S.
Department | of | Homeland | Security; | NIST/ASTM, | 2017. | URL:
https://www.nist.gov/system/files/documents/el/isd/ms/DHS_NIST_ASTM_Robot_Test_Methods-2.pdf (https://www.nist.gov/system/files/documents/el/isd/ms/DHS_NIST_ASTM_Robot_Test_Methods-2.pdf)
[2] ASTM E54.09, NIST. Response Robots—Ground Tests: Exploration and Mapping (2022A). ASTM/NIST, 2022.
[3] Engineering Toolbox. Angle of Repose for Bulk Materials, 2024. URL: https: //www.engineeringtoolbox.com/dumping-angles-d_1531.html
[4] Downey, R. Types of Building Collapse. FDNY Training Bulletin, 2001. URL: https://www.chiefraymonddowney.com/documents/wnyf/2001%20January%20-%20Types%20of%20Collapse.pdf (https://www.chiefraymonddowney.com/documents/wnyf/2001%20January%20-%20Types%20of%20Collapse.pdf)
[5] Riedl, M. и др. Synchronization in Collectively Moving Inanimate and Living Active Matter // Nature Communications. 2023.
[6] Hidalgo-Caballero, S., Cassinelli, A., Fort, E., Labousse, M. Frugal Random Exploration Strategy for Shape Recognition Using Statistical Geometry // Physical Review Research. 2024. Vol. 6, № 023103.
[7] USAR exploration metrics. Urban Search and Rescue—Exploration & Mapping Metrics, 2019.
[8] Harvard SEAS. Programmable Self-Assembly in a Thousand-Robot Swarm, 2014. URL: https://www.youtube.com/watch?v=6aZbJS6LZbs
[9] Harvard SEAS. Kilobot Swarm, 2011. URL: https://www.youtube.com/watch?v=RMjtmsr3CqA (https://www.youtube.com/watch?v=RMjtmsr3CqA)
[10] Systems and Methods for Foldable/Compact Aerial Robots. Патент
US11448728B2, | 2022. | URL | https://patents.google.com/patent/
US11448728B2 (https://patents.google.com/patent/US11448728B2)
[11] A Compact Morphing Drone for Confined-Space Inspection // Science
Robotics. | 2024. | URL: | https://www.science.org/doi/10.1126/
scirobotics.aee7991 (https://www.science.org/doi/10.1126/scirobotics.aee7991)
[12] Recent Advances in Confined-Space Robotics / Morphing Mechanisms // Nature Communications. 2024.
[13] Wang, Z., Appleton, E. The Bristle Theory and Traction Experiment of a Brush-Based Rescue Robot // Robotica. 2003.
[14] Romanishin, J. W., Gilpin, K., Claici, S., Rus, D. 3D M-Blocks: Self-Reconfiguring Robots Capable of Locomotion via Pivoting in Three Dimensions. 2015.

[15] Fath, M. и др. MARSBot: A Bristle-Bot Microrobot with AR Steering Control. 2024.
[16] Fath, M. и др. HeSARIC: A Heterogeneous Cyber-Physical Robotic Swarm Framework. 2025.
[17] Farrell, J. WiFi Imaging: Generating Building Maps Using Passively Received WiFi Signals., 2021.
[18] Yakub, A. Presence Detection with Wi-Fi Using ESP32. 2024.
[19] Geng, Z. и др. DensePose From WiFi. 2022.

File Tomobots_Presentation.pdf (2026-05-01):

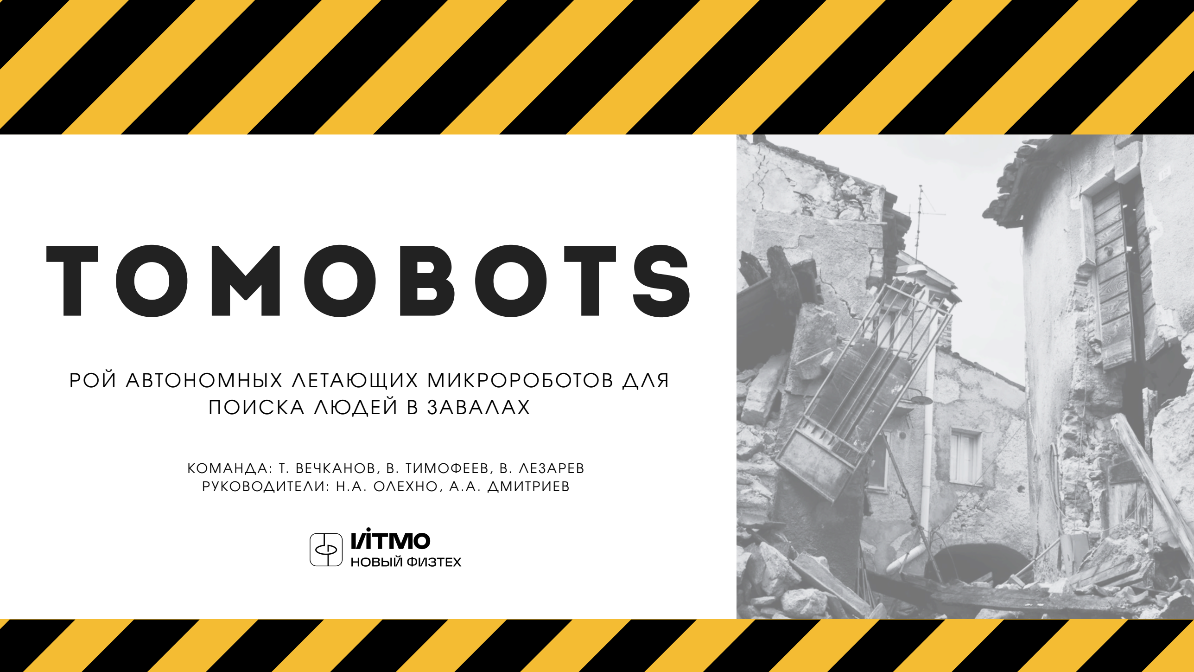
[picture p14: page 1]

# TOMOBOTS

РОЙ АВТОНОМНЫХ ЛЕТАЮЩИХ МИКРОРОБОТОВ ДЛЯ ПОИСКА ЛЮДЕЙ В ЗАВАЛАХ

КОМАНДА: Т. ВЕЧКАНОВ, В. ТИМОФЕЕВ, В. ЛЕЗАРЕВ РУКОВОДИТЕЛИ: Н.А. ОЛЕХНО, А.А. ДМИТРИЕВ

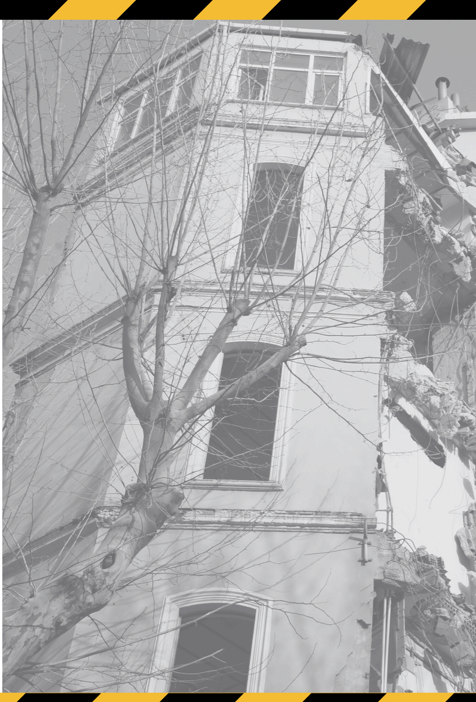
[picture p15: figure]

Узкие | щели | (20-30 | см), | неустойчивость
построек, пыль, нулевая видимость. Критический фактор — время. Существующие решения (гусеничные роботы) неэффективны.

КЛЮЧЕВОЙ ВОПРОС: КАК БЫСТРО И ЭФФЕКТИВНО ОБСЛЕДОВАТЬ НЕДОСТУПНЫЕ ПОЛОСТИ В ЗАВАЛЕ?

# ПРОБЛЕМА И АКТУАЛЬНОСТЬ

# КОНЦЕПЦИЯ РОЯ TOMOBOTS

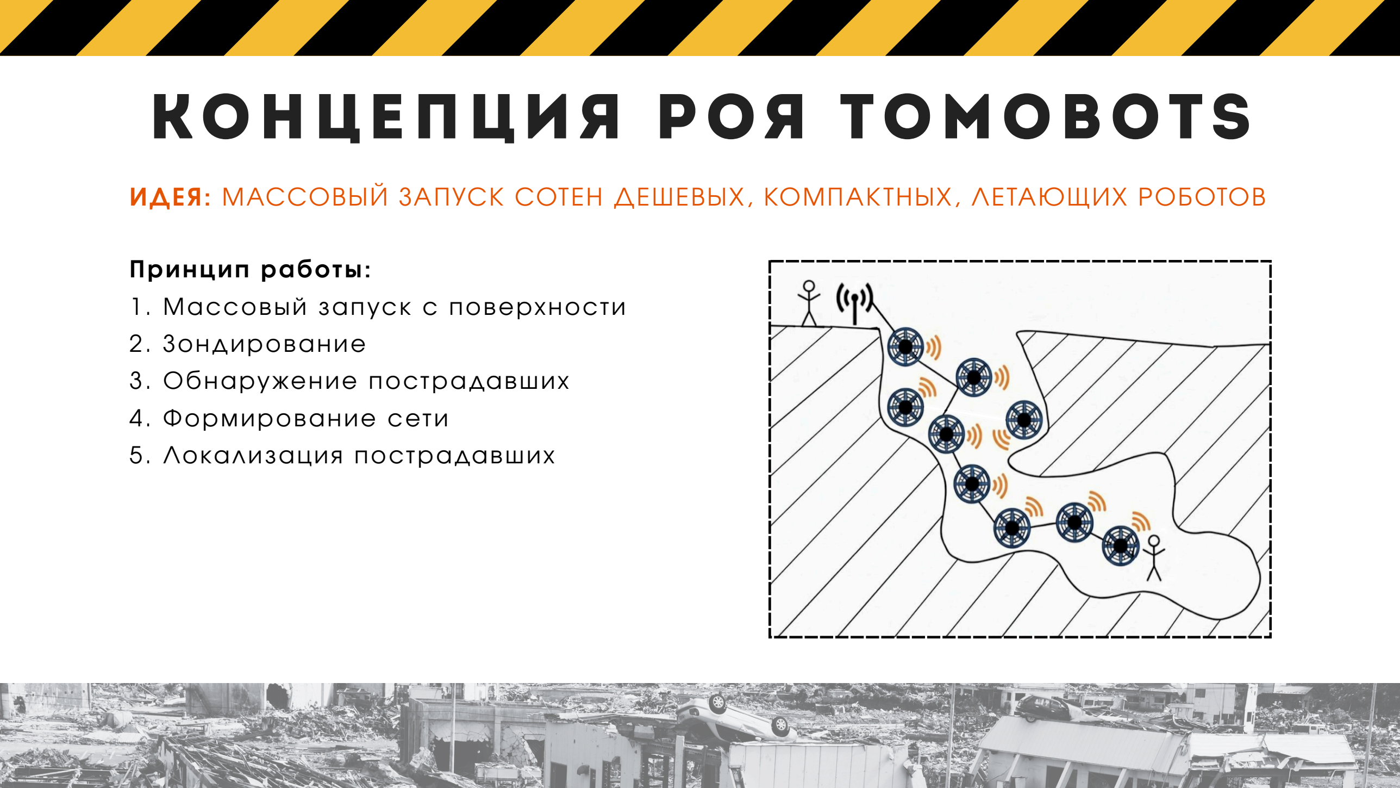
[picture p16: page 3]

ИДЕЯ: МАССОВЫЙ ЗАПУСК СОТЕН ДЕШЕВЫХ, КОМПАКТНЫХ, ЛЕТАЮЩИХ РОБОТОВ

Принцип работы:
1. Массовый запуск с поверхности
2. Зондирование
3. Обнаружение пострадавших
4. Формирование сети
5. Локализация пострадавших

# ПРОТОТИП

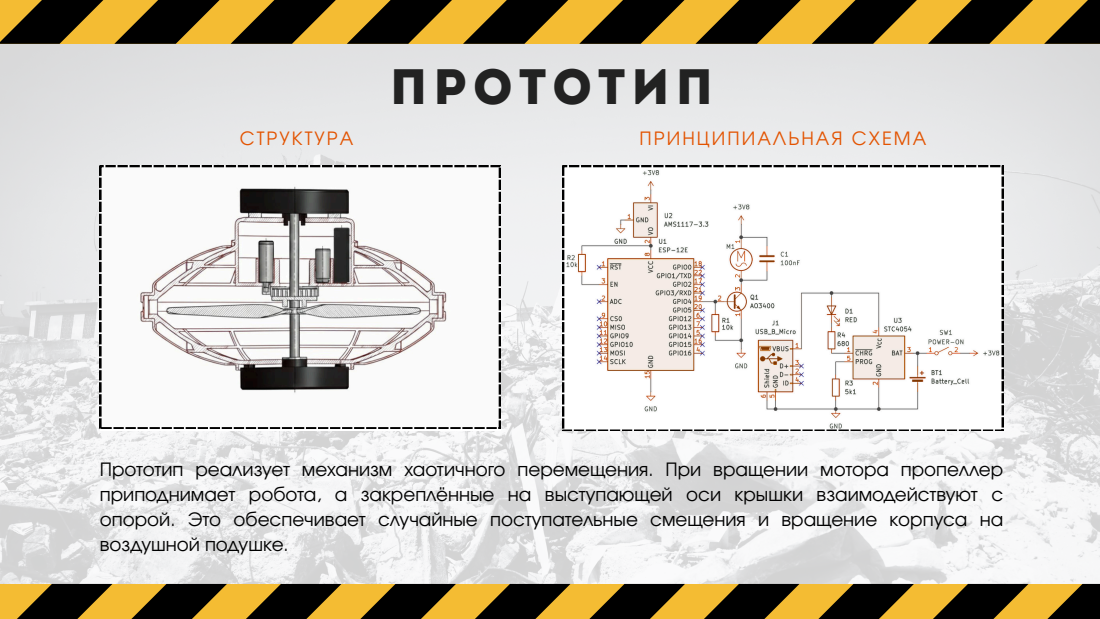
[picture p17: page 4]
СТРУКТУРА; ПРИНЦИПИАЛЬНАЯ СХЕМА

Прототип реализует механизм хаотичного перемещения. При вращении мотора пропеллер
приподнимает робота, а закреплённые на выступающей оси крышки взаимодействуют с
опорой. Это обеспечивает случайные поступательные смещения и вращение корпуса на
воздушной подушке.

# ПЛАН РАЗВИТИЯ

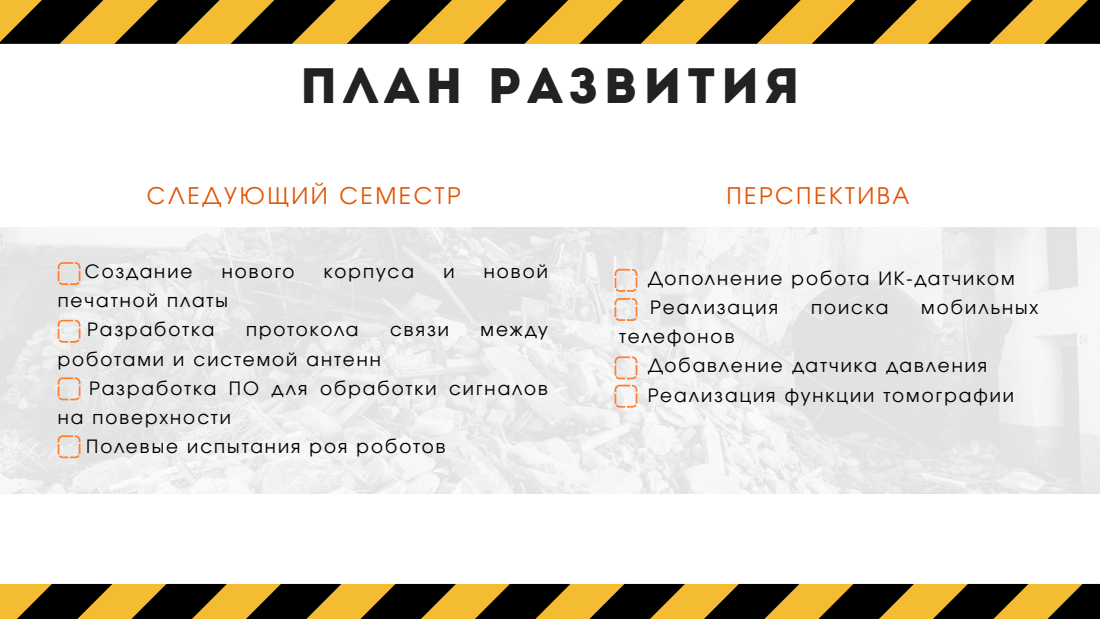
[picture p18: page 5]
Реализация; поиска; мобильных; Создание; нового; корпуса; новой; Разработка; протокола; связи; между; СЛЕДУЮЩИЙ СЕМЕСТР; ПЕРСПЕКТИВА

печатной платы
роботами и системой антенн
Разработка ПО для обработки сигналов
на поверхности
Полевые испытания роя роботов

Дополнение робота ИК-датчиком
телефонов
Добавление датчика давления
Реализация функции томографии

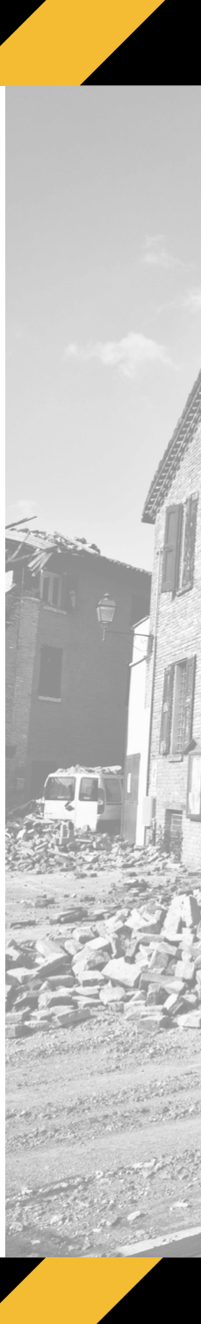
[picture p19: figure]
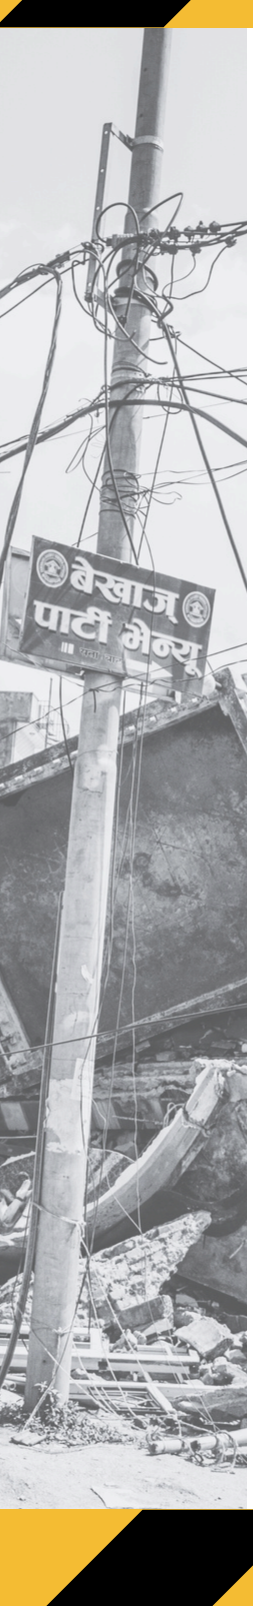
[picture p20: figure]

Вечканов Тимофей

timofei.vechkanov@metalab.ifmo.ru

Тимофеев Вячеслав

v.timofeev@metalab.ifmo.ru

Лезарев Всеволод

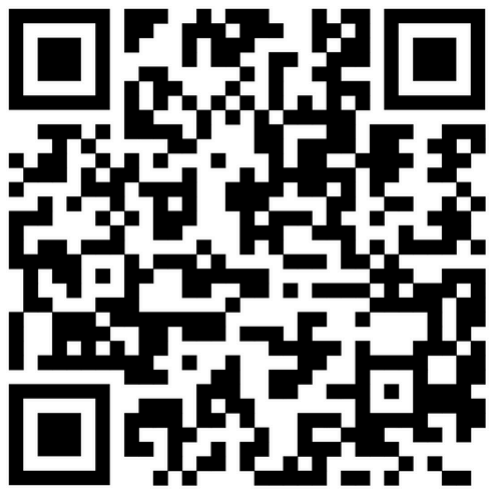
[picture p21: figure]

vsevolod.lezarev@metalab.ifmo.ru

Дмитриев Алексей

alexey.dmitriev@metalab.ifmo.ru

Олехно Никита

nikita.olekhno@metalab.ifmo.ru

# КОНТАКТЫ

КОМАНДА | РУКОВОДИТЕЛИ

### НАШ САЙТ

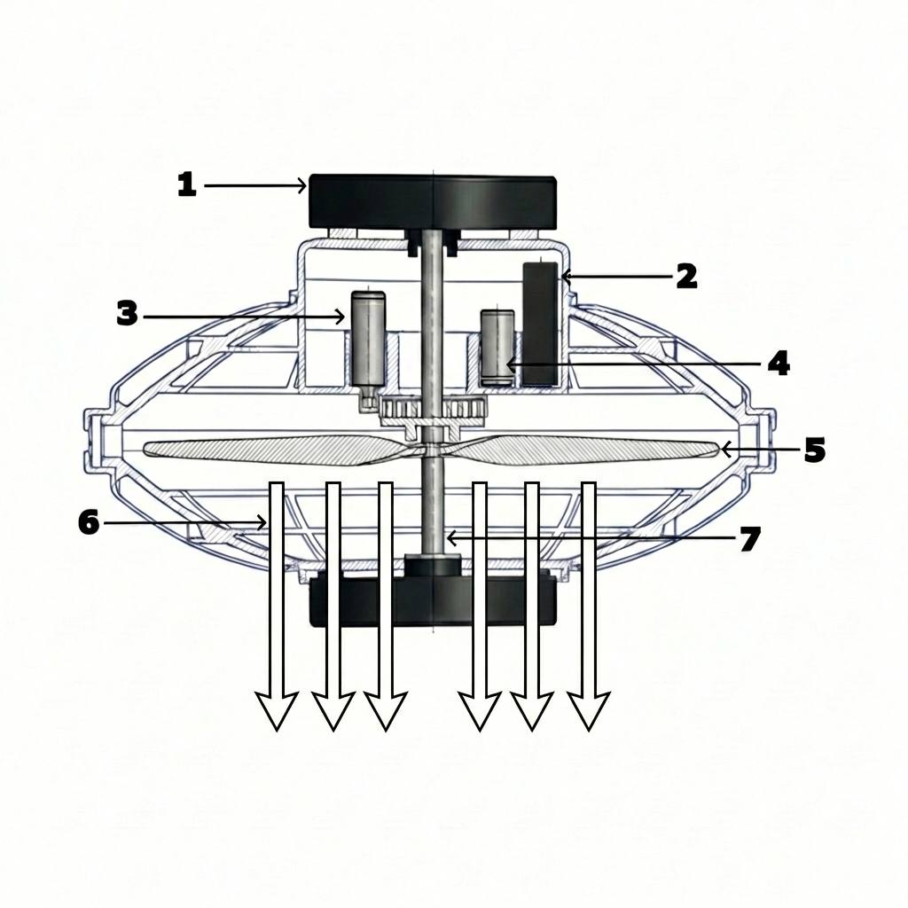
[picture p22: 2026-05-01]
TomoBot_Scheme.jpg

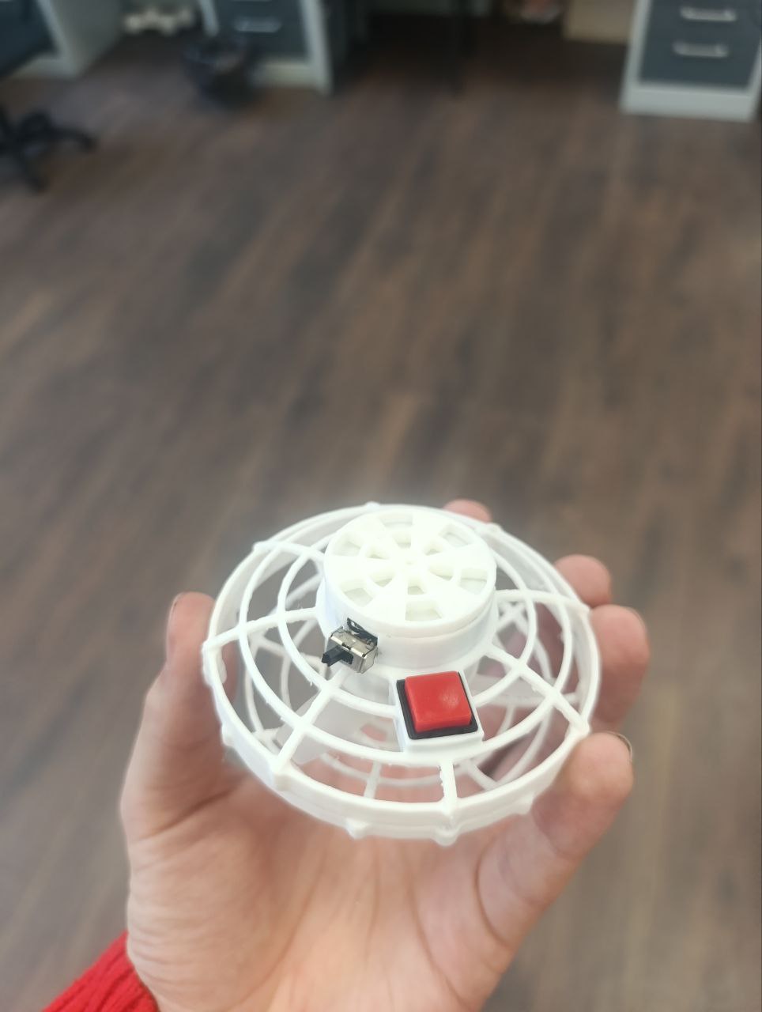
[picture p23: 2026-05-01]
Case/Photos/Real_photo_1.jpg

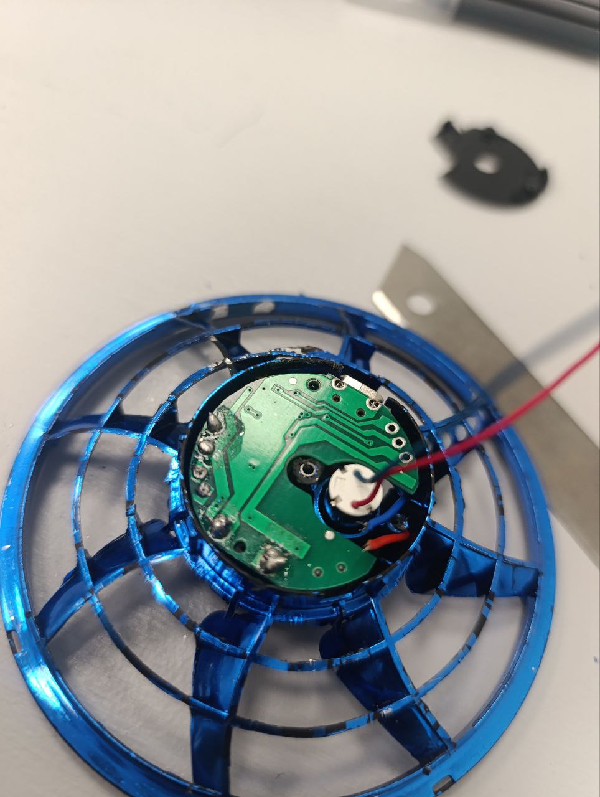
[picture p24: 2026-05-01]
Case/Photos/Real_photo_3.jpg

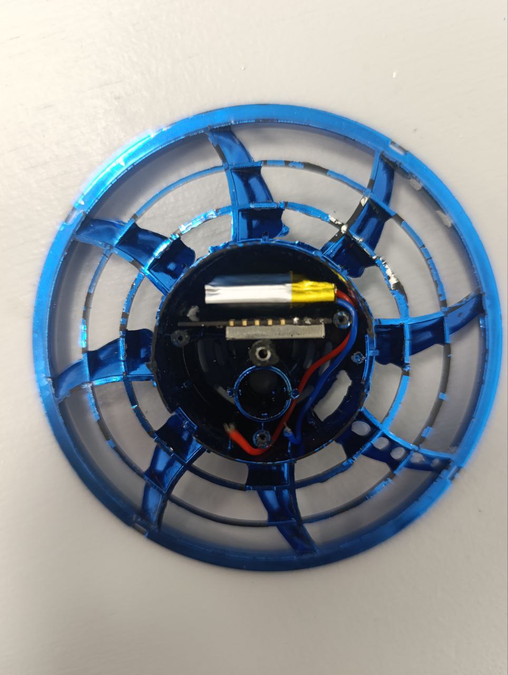
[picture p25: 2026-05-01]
Case/Photos/Real_photo_4.jpg

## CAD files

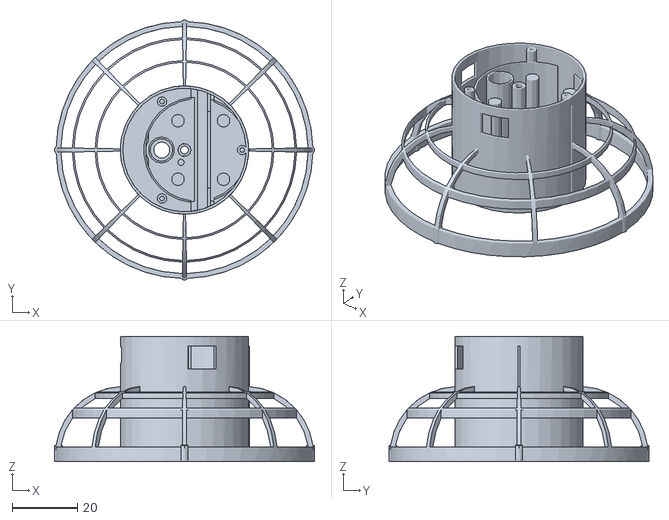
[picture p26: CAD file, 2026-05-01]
Case/3D_models/Upper_part.stl
80.0 x 80.0 x 38.5

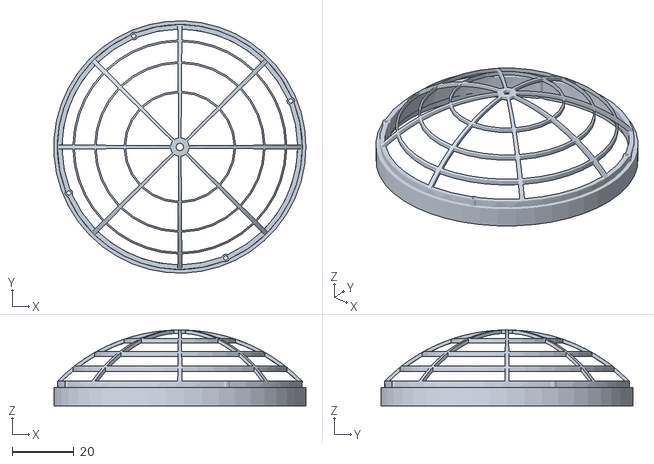
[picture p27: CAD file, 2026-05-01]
Case/3D_models/Lower_part.stl
81.3 x 81.4 x 24.5
